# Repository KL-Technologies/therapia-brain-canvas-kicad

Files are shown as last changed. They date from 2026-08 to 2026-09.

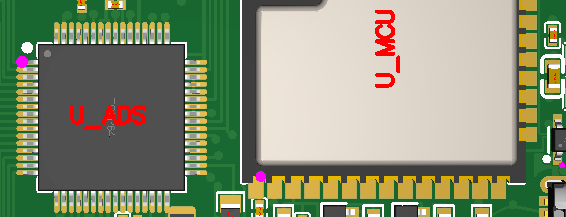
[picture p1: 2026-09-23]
fab/jlc_cart_2026-09-23_y9/08_placement_ads_mcu_pin1.png

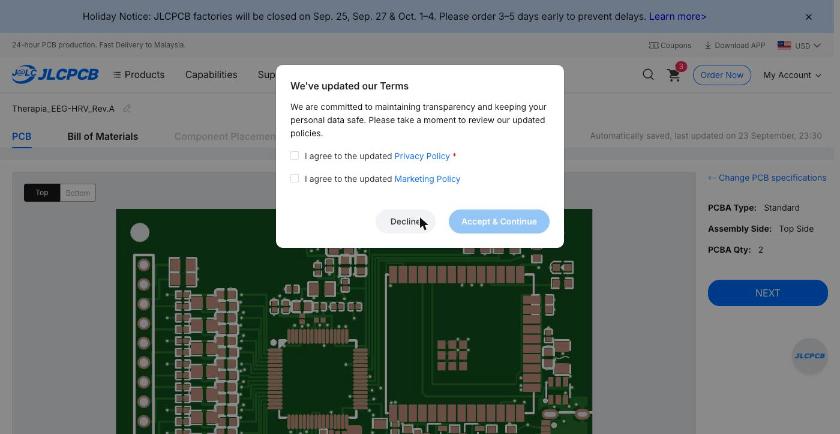
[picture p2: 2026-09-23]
fab/jlc_cart_2026-09-23_y9/03_terms_update_modal.jpg

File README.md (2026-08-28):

# brain_canvas_kicad

Brain Canvas Rev.A (Therapia EEG/HRV board) を **EasyEDA Pro から KiCad 10 へ移行**し、
以後のレイアウト修理・製造データ出力を KiCad 側でヘッドレスに回すためのパイプライン。

対象基板: 4層 / 61.8236 × 45.0088 mm (2434 × 1772 mil) / 部品 131 個・全数 Top 実装。

## 前提

| 名前 | パス | 用途 |
|---|---|---|
| `KC` | `/Applications/KiCad/KiCad.app/Contents/MacOS/kicad-cli` | DRC・Gerber 等の CLI（10.0.5） |
| `KPY` | `/Applications/KiCad/KiCad.app/Contents/Frameworks/Python.framework/Versions/Current/bin/python3` | `pcbnew` を持つ Python（3.9.13） |
| system `python3` | `/usr/bin/python3`（3.9.6） | 純 JSON 処理のステップ |

環境変数 `KC` / `KPY` で上書きできる。スクリプトは**標準ライブラリのみ**・**冪等**（再実行しても同じ結果）。
GUI は一切使わない。

## 使い方

```sh
./run.sh              # 未完のステップから順に実行（ゲート pass 済みは飛ばす）
./run.sh --status     # ゲート一覧を表示するだけ
./run.sh --force      # S0 から全部やり直す
./run.sh --from S2    # 指定ステップから再実行
./run.sh --no-commit  # git commit を作らない
```

ゲートが落ちると `exit 1` で停止する。**S1 の失敗は「.epro がまだ無い」待ち状態**であって
不具合ではない（`STATUS.md` 参照）。各ステップ成功後に `git commit` が入る。

```sh
python3 scripts/99_selftest.py   # 合成 .epro でパーサ／パッチャの動作確認（KiCad 不要）
```

## ステップ

| ID | スクリプト | 実行系 | 内容 | ゲート |
|---|---|---|---|---|
| S0 | `scripts/00_env_check.sh` | bash | kicad-cli / pcbnew / `EASYEDAPRO` / `ZONE_FILLER` / `drc --refill-zones` の存在確認 | `gates/S0.json` |
| S1 | `scripts/05_find_epro.sh` | bash + python3 | `~/Downloads` `~/Desktop` `~/Documents` `therapia-device/` から `.epro` / `.epro2` を捜して `import/` へ複製し sha256 記録 | `gates/S1.json` |
| S1B | `scripts/06_epro2_to_epro.py` | python3 | `.epro2`（EasyEDA Pro 3.2）を KiCad が読める旧 `.epro` へ変換。旧形式が既にあれば何もしない | `gates/S1B.json` |
| S2 | `scripts/10_epro_inventory.py` | python3 | `.epro` を自前パースして EasyEDA 側の員数表を作る | `gates/inventory_easyeda.json` |
| S2 | `scripts/11_import_epro.py` | KPY | パッチ段階を変えながら `PCB_IO_MGR.Load(EASYEDAPRO)` → `Save(KICAD_SEXP)` → パッド網の補修 → DRC | `board/*.kicad_pcb` |
| S2 | `scripts/12_verify_import.py` | KPY | `pcbnew.LoadBoard` で読み直して EasyEDA 側と突合 | `gates/S2.json` |
| S2B | `scripts/20_netlist_contract.py` | python3 | 回路図ネットリスト TSV を契約化し、PCB との差分（＝ECO-1 の残作業）を列挙 | `gates/S2B.json` |
| S4a | `scripts/13_fix_import.py` | KPY | NPTH 6 穴を合成（M2 ×4・USB-C ペグ ×2）し、開いていた基板外形を閉じる | `gates/S4a.json` |
| S3 | `scripts/14_make_rules.py` | python3 | JLC 4 層ルールを `.kicad_pro` / `.kicad_dru` / `.kicad_pcb` の `(setup)` へ生成 | — |
| S3 | `scripts/15_gate_s3.py` | python3 + KC | DRC ベースラインを取り、**ルールが L1〜L4 を実際に検出することを検定** | `gates/S3.json` |
| S4 | `scripts/19_make_parts_table.py` | python3 | 旧 BOM ＋ ECO-2/3 の置換表から `data/parts_lcsc.csv`（135 行）を生成 | — |
| S4 | `scripts/20_apply_eco.py` | KPY + KC | ECO-1/2/3 を PCB へ適用し、契約と全パッド突合、ゾーン再充填して DRC | `gates/S4.json` |
| S5_uuids | `scripts/26_fix_uuids.py` | python3 (+KPY) | 重複 KIID 2,625 個を採番し直す。**これより前の DRC レポートはアイテムの同定が信用できない** | `gates/S5_uuids.json` |
| S5_L1 | `scripts/30_repair_L1.py` | KPY + KC | AMS1117 を取付穴 H4 から退避させ、4 ピンを繋ぎ直す | `gates/S5_L1.json` |
| S5_L2 | `scripts/31_repair_L2.py` | KPY + KC | CHASSIS_GND を H1 の外へ引き直す | `gates/S5_L2.json` |
| S5_L3 | `scripts/32_repair_L3.py` | KPY + KC | ESP_TXD を分割し、H4 に掛かる中央だけ引き直す | `gates/S5_L3.json` |
| S5_L4 | `scripts/33_repair_L4.py` | KPY + KC | USB-C ペグ穴 PEG1/PEG2 を空け、J1 の GND ランドを詰める | `gates/S5_L4.json` |
| S5_L5 | `scripts/34_repair_L5.py` | KPY + KC | 残りの近接を幾何から洗い出して解消 | `gates/S5_L5.json` |
| S5_mask | `scripts/35_mask_bridges.py` | KPY + KC | 合体したレジスト開口をパッド個別マージンで分ける | `gates/S5_mask.json` |
| S6 | `scripts/40_drc_loop.py` | python3 + KPY + KC | DRC → 修正 → DRC を clean になるまで反復 | `gates/S6.json` |
| S7a | `scripts/45_apply_eco5_and_bom.py` | KPY + KC | ECO-5（`C_BIAS_INV` pad2 を GND → BIAS_OUT_INT）と BOM 修正・DNP 2 点を反映 | `gates/S7a.json` |
| S7b | `scripts/46_analog_untouched.py` | KPY | 取り込み直後の基板とアナログ 40 ネットを突合し、差分の由来を記録から特定 | `gates/S7b.json` |
| S7c | `scripts/48_improve_vcap3.py` → `47_layout_quality.py` | KPY | バイパス C を「より近く・ビア無し」の位置へ移せるか試し、ADS1299 チェックリスト J1〜J11 を実測 | `gates/S7c.json` |
| S8 | `scripts/43_fix_pth_mask.py` → `49_normalize_layer_names.py` → `60_export_fab.sh` → `61_make_bom_cpl.py` → `63_gate_s8.py` | KPY + KC + python3 | PTH のレジスト開口を復旧し、レイヤ名を正規化してから Gerber・ドリル・BOM・CPL・プレビューを出力し、**自前パーサ**で検査 | `gates/S8.json` |
| S7 | `scripts/50_final_check.py` | KPY + KC | **ACCEPTANCE A〜G を 32 項目で判定** | `gates/S7.json` |

**S8 が S7 より先なのも意図的**。ACCEPTANCE の D〜G は S8 が出力した製造データを
読むので、先に出力しないと最終ゲートに検査対象が無い。

**S4a が S3 より先なのは意図的**。取付穴が NPTH になるまで hole clearance ルールに
引っかかる穴が存在せず、S3 のゲート（L1/L2/L4 の検出）が成立しないため。

**S5_uuids が L1 より先なのも意図的**。KiCad の DRC は違反アイテムを KIID で保存して
レポート時に引き直すので、KIID が重複していると**別の部品を名指しする**。
取り込み直後の基板は 231 個の uuid を共有していた（1 個は 38 部品で共有）。

### 共通ライブラリ

| ファイル | 中身 |
|---|---|
| `scripts/lib/epro.py` | `.epro` のパースとパッチ、ゲート JSON の読み書き |
| `scripts/lib/route.py` | 銅箔の空間索引・衝突判定、スタブ除去、2 層ルータ（直線→L 字→via ホップ）、部品配置探索 |
| `scripts/lib/maze.py` | 2 層 A* ルータ。via 遷移つき、DRC と同じ `SHAPE::Collide` で判定し、経路は採用前に線分ごとに再検証してから直線化する。ペグ穴まわりのように「直線も L 字も via ホップも無い」場所はこれでないと通らない |
| `scripts/lib/repair.py` | S5/S6 共通。ルール値、穴までの距離、接続性（`net_components`）、修理プリミティブ（via 退避・端点退避・トラック分割迂回・穴の排除）、ゲート雛形 |
| `scripts/lib/viol.py` | DRC レポートを作業リストに変換する。ただし**位置は信用しない**（アイテム自身のアンカーが入っている） |
| `scripts/lib/drc.py` | DRC レポートの署名比較。`kicad-cli pcb drc` は同一入力で 525〜531 件と揺れるので、件数ではなく（種別, ネット集合）で比較する |
| `scripts/lib/xlsx.py` | 旧 BOM/CPL の xlsx を標準ライブラリだけで読む |
| `scripts/lib/gerber_parse.py` | RS-274X と Excellon を**自前で**読む（標準ライブラリのみ）。C/R/O/P アパーチャ、KiCad の `RoundRect` マクロ、G36/G37 リージョン、G75 円弧、LPD/LPC 極性。未知のマクロは外接円に落とす（穴クリアランス検査で銅を過大評価する側なので、誤警報は出しても見逃しは出さない）。**KiCad に自分の出力を読み直させても、自分と矛盾していないことしか分からない** — S8 の PTH レジスト欠落はこれで見つかった |

`import/` に**正規の旧 `.epro`** と `.epro2` が両方あるときは、必ず旧 `.epro` を使う（変換を挟まないぶん確実）。
`.converted.epro` は最下位。

## 落とし穴 3 つ（実測で確認済み）

### 1. `.epro2` は KiCad 10.0.5 では読めない。しかもエラーが出ない

EasyEDA Pro 3.2 の書き出しは `project2.json` ＋ 単一の `.epru`（全ドキュメントを
`{ヘッダ}||{本体}|\n` で連結したログ形式）。KiCad のバイナリに `project2.json` / `epru` /
`epro2` の文字列は 1 つも無く、`PCB_IO_MGR.Load` に渡すと **例外を出さずに空の基板
（フットプリント 0・ネット 1）を返す**。気づかず先へ進める形の失敗なので、S1 で形式を判定し
S1B で変換する。変換で運ばないもの:

- `RULE` — 3.2 の設計ルールは入れ子構造で旧形式への対応が付かない（これを誤ると #24303 を踏む）。値は `contract/easyeda_rules.json` に出すので S3 が `.kicad_pro` へ意図して書き写す
- `POURED` — EasyEDA が計算済みの銅箔充填。KiCad が `drc --refill-zones` で作り直すし、S3 は編集後にどのみち再充填が要る

### 2. 同じ番号のパッドは 1 つしかネットが付かない

KiCad は `PAD_NET` を `FindPadByNumber()` で当てるので、**同一番号のパッドが複数あると最初の 1 枚
にしか付かない**。この基板では ESP32 のサーマルパッド（`39` ×9）と USB-C のシェル脚
（`13`/`14` ×2）が該当し、GND が 10 パッド落ちる。`11_import_epro.py` が取り込み後に
EasyEDA 側の表を全パッドへ再適用して直す（`logs/pad_net_repair.json`）。

### 3. `kicad-cli pcb drc` はコマンドサンドボックス内では動かない（かつ非決定的）

サンドボックス下では `Swift/SwiftNativeNSArray.swift:78: Fatal error: Array index out of range`
で落ちる（Swift のエラーは表面的な症状で、原因は macOS のサービスが塞がれていること）。
`export gerbers` などほかのサブコマンドは影響を受けない。**DRC はサンドボックス外で実行する。**
通常のターミナルからは普通に動く。

さらに **DRC の出力は同一の基板に対しても揺れる**。実測で 525 / 528 / 531 件。
同じ物理的問題を代表する要素の選ばれ方が変わるためで、たとえば

```
run A   Track [V_NLDO_IN] on Bottom Layer, length 2.2860 mm  <-> Via [VNEG5]
run B   Track [V_NLDO_IN] on Bottom Layer, length 0.2543 mm  <-> Via [VNEG5]
```

は同じ 1 箇所を指している。したがって**件数で合否を判定してはいけない**。
`scripts/lib/drc.py` の署名（種別 ＋ ネット集合）で比較する。
部品参照を署名に含めてはいけない ── track（部品名を含まない）と pad（含む）が
入れ替わるだけで、無変更の基板が「新規 10 件・解決 10 件」に見える。

### 4. KIID は一意ではない（この基板では 231 個が重複）

EasyEDA インポータがライブラリ部品の全インスタンスに同じ KIID を振る。実測で
**38 個の部品が 1 個の uuid を共有し、その 38 個の 1 番パッドがまた別の 1 個を共有**。
KiCad は uuid の一意性を前提にしていて、`BOARD::GetItem(KIID)` は最初に見つけた
ものを返す。

これが効いてくるのは **DRC レポート**で、KiCad は違反アイテムをポインタではなく
KIID で保存し、レポートを書くときに引き直す。重複があるとレポートは
**実在しない組み合わせを名指しする** ── 9.3 mm 離れたパッド同士の
`solder_mask_bridge`、8.9 mm 離れたパッド同士の 0.0420 mm `clearance` など。
**種別と件数は常に正しく、間違うのはアイテムの同定だけ。**

`scripts/26_fix_uuids.py` が重複を採番し直す（`.kicad_pcb` は uuid を相互参照
しないので安全。基板の幾何とネットが不変であることを検証してから保存する）。
**取り込みからやり直す場合は L1 より先にこれを通すこと。**

### 5. pcbnew の SWIG プロキシは `id()` で比較できない

基板から同じパッドを 2 回取り出すと別のプロキシが返り、`id()` が一致しない。
無視リストや訪問済み集合は `scripts/lib/route.uid()` で持つこと
（KIID 単独では上記のとおり一意でないので、パッドと部品は reference と
フットプリント相対座標を足した鍵になっている）。関連して:

- `board.Remove()` は board 直下の要素に使うと以後 `GetFootprints()` が生の
  `SwigPyObject` を返すようになる。**`RemoveNative()` を使う**
- `pcbnew.FOOTPRINT(src)` は KIID ごと複製する（複製先のパッドが元と同じ uuid を持つ）。
  `m_Uuid` は書き込み不可で `FixUuids()` も効かないので、新規部品はゼロから組み立てる
- 同一プロセスでの 2 回目の `LoadBoard`、および `SaveBoard` の後は基板を走査できない。
  計測は保存前に済ませる

## KiCad 側インポータの既知バグと回避

`.epro` は ZIP の中に JSON Lines 文書（`project.json` / `*.epcb` / `*.esch` / `*.esym` / `*.efoo`）が入る形式
（仕様: <https://dev-docs.kicad.org/en/import-formats/easyeda/index.html>）。
KiCad 10 のインポータは現行の EasyEDA 出力に対して 2 つ落とし穴がある。

| KiCad issue | 症状 | 回避 |
|---|---|---|
| #24303 | パースが `type must be number, but is array` で落ちる。EasyEDA 2.2+ の `RULE` レコードが payload を 1 段深い dict に入れるため | `RULE` の `ruleData` を旧形式へ平坦化（clearance=`ruleType "1"` / track width=`"3"`） |
| #19021 | 読み込みは成功するのに**全パッド・全トラックが 1 ネットに融合**する。新しい出力が先頭の `NET` 宣言を落とすため | 各プリミティブの net 名フィールドを走査して、未宣言のネットを `["NET", name]` としてヘッダ直後に再注入 |
| （併発） | `std::out_of_range: map::at` で落ちる | 文書内の CRLF を LF へ正規化 |

手法は <https://github.com/enkhbold470/epro2kicad> を参照して `scripts/lib/epro.py` に自前実装した
（外部依存としては入れていない）。`11_import_epro.py` は

`raw` → `newlines` → `newlines+rules` → `newlines+rules+nets`

の 4 段階をそれぞれ**別プロセスの KPY で**試し（パーサが abort しても子プロセスだけが死ぬ）、
`gates/inventory_easyeda.json` の員数と突き合わせて**一番手を加えていないのに員数が合う段階**を採用する。
採用結果は `logs/import_attempts.json` / `logs/import_summary.json` に残る。

## 単位と座標

- EasyEDA Pro の PCB 内部単位は **mil**、**y は下向きが負**。`mm = mil × 0.0254`。
- KiCad は内部単位 nm、**y は下向きが正**。したがって EasyEDA の点 `(x, y)` は KiCad の `(x, −y)` に対応する。
- さらに KiCad は取り込み時に基板を **(120, 80) mm** 平行移動する（実測値。`gates/S2.json` の
  `board_offset_mm` に毎回記録される）。**S3 以降で EasyEDA 由来の座標メモ
  （`11_rev_a_eco_2026-08-16.md` の L1〜L6 など）を KiCad 上で使うときは
  `kicad = (x + 120, −y + 80)` [mm] で読み替えること。**
- 部品ローカル座標 → 基板座標は単純な回転（軸反転なし）:
  `bx = cx + lx·cosθ − ly·sinθ` / `by = cy + lx·sinθ + ly·cosθ`。
  `10_epro_inventory.py` が毎回 131 部品分を `fab_2026-08-16` の CPL（Pad X/Pad Y）と突き合わせて
  検証する（`cpl_crosscheck.placement_transform_verified`）。

## ディレクトリ

```
import/    .epro 原本（SHA256SUMS 付き）と patched.epro
board/     KiCad 成果物 (.kicad_pcb / .kicad_pro)
scripts/   パイプライン本体（lib/ は共通パーサ）
gates/     各ステップの合否 JSON と員数表
contract/  ネットリスト（S3 の契約）
fab/       製造データ（S8）。zip・BOM・CPL・プレビュー・実装図・README_発注手順.md
logs/      実行ログ・DRC 出力・パッチ試行履歴
```

## 参照する既存資料（読むだけ・変更しない）

- `../cerelog_research/11_rev_a_eco_2026-08-16.md` — ECO-1〜3 とレイアウト修理 L1〜L6 の正本
- `../cerelog_research/PROJECT_STATUS.md` — 経緯・ネット員数の記録
- `../cerelog_research/fab_2026-08-16/` — 旧版の Gerber / BOM / CPL。CPL の 131 designator と
  回転角は S2 の独立参照として自動で突合される

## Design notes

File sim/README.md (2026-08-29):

# `sim/` — headless SPICE for Brain Canvas Rev.A

Circuit simulation of the board as the contract netlist wires it, run
head­lessly from Python. No GUI, no ngspice CLI, no LTspice, no PySpice.

```
python3 sim/run_all.py            # every case -> gates/S3_sim.json
python3 sim/cases/drl_loop.py     # one case  -> sim/out/drl_loop.json
python3 sim/lib/ngspice_ctypes.py # self-test the engine
```

Use `/usr/bin/python3` (3.9, arm64). The KiCad-bundled interpreter at
`/Applications/KiCad/KiCad.app/Contents/Frameworks/Python.framework/Versions/Current/bin/python3`
works identically.

## The engine

KiCad 10.0.5 ships the full ngspice shared library, so there is no need to
install anything:

```
/Applications/KiCad/KiCad.app/Contents/Frameworks/libngspice.0.dylib   ngspice-45.2
/Applications/KiCad/KiCad.app/Contents/PlugIns/sim/ngspice/*.cm        XSPICE code models
```

`sim/lib/ngspice_ctypes.py` drives it through the classic sharedspice API
(`ngSpice_Init` / `ngSpice_Command` / `ngGet_Vec_Info`). Both interpreters
`dlopen` it without any codesign or Library Validation trouble — the library
is already signed as part of the KiCad bundle, and both it and the
interpreters are arm64.

Every netlist runs in **its own subprocess**. libngspice keeps global state
and can tear the process down on a fatal error, so isolating each run makes a
blown-up simulation a recoverable event and guarantees circuit N+1 inherits
nothing from circuit N.

## Layout

| Path | What it is |
|---|---|
| `lib/ngspice_ctypes.py` | ctypes driver; `run_netlist(deck) -> SimResult` |
| `lib/extract_subckt.py` | contract netlist + BOM → SPICE elements, with DC-bias derating |
| `lib/simutil.py` | measurement helpers (ripple, settling, phase margin) and the result format |
| `models/behavioral.lib` | behavioural models (TLV70025, AMS1117, ADS1299 BIAS amp, S8050) |
| `models/vendor/` | TI's unencrypted PSpice models for LM2664 and TPS723xx, used **unmodified**, plus thin board-pinout wrappers |
| `models/PROVENANCE.md` | **read this before believing a number** |
| `data/cap_derating.json` | per-LCSC MLCC DC-bias retention, ESR, ESL |
| `cases/*.py` | one script per test, each writing `sim/out/<case>.json` |
| `run_all.py` | runs them all, writes `gates/S3_sim.json` |

## Nothing is typed in twice

Component values and connections are read from
`contract/netlist_easyeda_api_2026-08-28.tsv` and `data/parts_lcsc.csv`, with
`contract/contract_overrides.json` (ECO-5) applied by default. A case script
asks for a set of designators or nets and gets SPICE back:

```python
from extract_subckt import Design
d = Design()                       # as built (overrides applied)
d.numeric_value("R_BIAS_FB")       # 1e6   -- "1M" is megohms, not milliohms
text, report = d.spice(nets=["AVSS"], bias={"AVSS": -2.5, "GND": 0.0})
```

`report["skipped"]` lists everything that was *not* emitted and why, so a
case can prove it did not silently drop a component.

## Vendor models

TI's unencrypted PSpice models are used for the two devices where one exists:

* **LM2664** — SNVMBY1, verbatim. Real oscillator, real 1.25 Ω switches,
  real SD comparator.
* **TPS72325** — SLVMBZ8 (the adjustable TPS72301), re-parameterised to
  −2.5 V. Its enable term is `IF(ABS(V(enb)) > 1.5)`, which is how the
  simulation confirms the board's EN wiring rather than assuming it.

`TLV70025`'s TI model is encrypted and the AMS1117 has none, so those two are
behavioural. `models/PROVENANCE.md` has the full table.

ngspice parses TI's PSpice text unmodified once `set ngbehavior=psa` is
issued **before** the deck is sourced — `run_netlist(..., pre_commands=[...])`.
A `.options` line inside the deck is too late.

## Capacitor derating is not optional here

Every ceramic on this board is class II. `C_NLDO_OUT` is a 2.2 µF 6.3 V X5R
in 0402 biased at 2.5 V; simulating it as 2.2 µF would be self-deception.
The harness derates from `data/cap_derating.json` and totals what is really
there — AVDD and AVSS each lose about 52 % of their marked
capacitance at typical 25 C bias, and about 64 % in the worst corner.

Nine of the eleven rows are **fetched Samsung curves** (weblib, 25 °C,
2026-08-29) and are flagged `trusted: true`; one is a documented estimate and
says so. Each row also carries a worst-case curve — the measurement times the
tolerance low limit times 0.85 for the temperature coefficient — and
`ldo_stability.py` reports both corners, plus a current-versus-proposed BOM
comparison.

Three things the real curves show that a rule of thumb would miss: a 50 V
1206 part still loses 20 % at 5 V; a 25 V 0402 1 µF loses 38 % at 3.3 V (that
is C_EN_DLY, and it is why the ESP32 reset-delay check fails); and a 100 µF
6.3 V 1206 is only 91 µF before any bias is applied.

## Cases

| Case | Asks |
|---|---|
| `power_tree_startup.py` | USB hot-plug at 4.75 / 5.25 V through F1 → AMS1117, TLV70025, LM2664 → TPS72325. Rail values, rise, overshoot, AVSS ripple, and whether TPS72325's EN is asserted |
| `ldo_stability.py` | Loop gain and load-step settling for both analog LDOs on the *derated* output capacitance |
| `drl_loop.py` | ADS1299 BIAS loop through an electrode/body model at 5 k / 20 k / 100 kΩ skin, with the BIAS amp's unpublished GBW swept 10 kHz…1 MHz. Also runs the pre-ECO-5 wiring to quantify what that ECO bought |
| `esp32_autoreset.py` | DTR#/RTS# truth table against esptool's reset sequence, ESP32 pin levels against absolute maximum, and the power-on EN delay |

## ngspice traps worth knowing

Found the hard way while building this; all are silent failures.

1. **`limit(x, lo, hi)` in a B-source returns 0 and raises no error.** It is
   not an ngspice B-source function. Use `min(max(x, lo), hi)`.
2. **`GND` is a reserved global alias for node 0.** A sub-circuit terminal
   named `GND` is silently shorted to ground. The models here use `GNDP`.
3. **A `? :` step on a node that multiplies a current is a discontinuity the
   solver cannot cross** — it shows up as `Timestep too small`. Enable
   comparators here ramp over a narrow window instead.
4. **A fixed DC current sink on a rail that is still at 0 V** drives the t=0
   operating point to kilovolts through whatever leakage resistor the model
   has, and the transient never starts. Loads are gated on their own rail.
5. **An error amplifier with no anti-windup** runs away while its regulator
   is disabled and then demands kiloamps on the first step after enable.
6. `.options rshunt=1e9 cshunt=2f` cures most remaining stiffness.
7. **`set ngbehavior=psa` must be issued before the deck is sourced**, not as
   a `.options` line inside it.
8. **ngspice 45.2's PSpice mode has a start-up race** that kills the library
   roughly half the time with `failed to parse .func in: .func pwr(x a)`.
   Loading the XSPICE code models makes it much less likely (3 in 6 versus
   6 in 6 without); `run_netlist` retries eight times to cover the rest.
   Because of this, PSpice mode is switched on only for decks that actually
   contain a vendor model.
9. **Passing the same node to two formals of a sub-circuit** can stall a
   transient. The board ties LM2664 SD to V+ and TPS72325 EN to IN, so both
   vendor wrappers insert a 1 mΩ isolation resistor.
10. TI's vendor models are stiff enough that they will not converge inside
    the full power-tree deck; each runs in its own focused deck instead.

## Possible future replacement

[`spicelib`](https://github.com/nunobrum/spicelib) offers a common API over
ngspice and LTspice plus Monte Carlo / worst-case tooling, and would be a
reasonable replacement for `lib/ngspice_ctypes.py` if tolerance analysis is
ever wanted. Not adopted now: it needs a `pip` install, which the command
sandbox blocks, and the ctypes driver already does what these cases need.

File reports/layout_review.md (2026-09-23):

# レイアウト品質レビュー（S7c）

`docs/ads1299_layout_checklist.md`（一次資料ベース、opusQ3）の **J1〜J11** と、S7 への申し送りが挙げた点を、**基板から実測**して答えたもの。

> **距離に閾値を置いていないのは意図的。** チェックリストが冒頭で 「TI はデカップリングの配置距離を一切数値で示していない。『◯ mm 以内』という数字を作ってはいけない」と釘を刺している。したがって距離は**測定値として載せるだけ**で合否にしない。TI が規則として書いているのは J1（バイパス C と IC の間にビアを置かない・同一層）なので、合否はそちらで取る。

## 1. デカップリング — J1（ビアを挟まない・同一層）

DS §12.1: *"Do not place vias between bypass capacitors and the active device. Placing the bypass capacitors on the same layer as close to the active device yields the best results."*

> **J1 が効くのは配線で配る電源だけ。** この基板でベタになっているのは `AVDD`, `AVSS`, `CHASSIS_GND`, `GND`, `USB_5V`, `VDD_ESP`。ベタ電源はパッド→ビア→ベタ→ビア→ピンで繋がるので、「経路にビアがある」のはスタックアップの性質であってレイアウトの誤りではない。配線で配っている **VCAP1〜4 と VREFP** が J1 の対象。

| コンデンサ | ADS ピン | 配り方 | 直線 [mm] | 銅箔経路 [mm] | 経路上のビア | 同一層 | J1 | 戻り側 | 戻り via まで [mm] |
|---|---|---|---|---|---|---|---|---|---|
| C_AVDD_P19 | 19 (AVDD) | ベタ | 3.10 | 配線経路なし | — | はい | — | GND | 0.83 |
| C_AVDD_H | 21 (AVDD) | ベタ | 8.47 | 配線経路なし | — | はい | — | GND | 0.77 |
| C_AVDD_B | 21 (AVDD) | ベタ | 8.62 | 配線経路なし | — | はい | — | GND | 0.78 |
| C_AVDD_H | 22 (AVDD) | ベタ | 8.39 | 配線経路なし | — | はい | — | GND | 0.77 |
| C_VREFP_10u | 24 (VREFP) | 配線 | 6.46 | 9.40 | 0 | はい | OK | AVSS | 1.03 |
| C_VREFP_100n | 24 (VREFP) | 配線 | 3.40 | 6.47 | 0 | はい | OK | AVSS | 1.96 |
| C_VREFP_10n | 24 (VREFP) | 配線 | 2.93 | 2.65 | 0 | はい | OK | AVSS | 1.97 |
| C_VCAP4 | 26 (VCAP4) | 配線 | 1.36 | 1.36 | 0 | はい | OK | AVSS | 1.83 |
| C_VCAP1 | 28 (VCAP1) | 配線 | 9.89 | 17.40 | 2 | はい | **NG** | AVSS | 0.95 |
| C_VCAP1_H | 28 (VCAP1) | 配線 | 1.36 | 1.36 | 0 | はい | OK | AVSS | 2.51 |
| C_VCAP2 | 30 (VCAP2) | 配線 | 1.53 | 1.53 | 0 | はい | OK | AVSS | 0.94 |
| C_AVDD_P36 | 56 (AVDD) | ベタ | 16.29 | 配線経路なし | — | はい | — | GND | 1.02 |
| C_AVDD_P31 | 56 (AVDD) | ベタ | 14.13 | 配線経路なし | — | はい | — | GND | 2.10 |
| C_AVDD1_1u | 54 (AVDD1) | ベタ | 4.10 | 配線経路なし | — | はい | — | AVSS | 1.64 |
| C_AVDD1_100n | 54 (AVDD1) | ベタ | 3.95 | 配線経路なし | — | はい | — | AVSS | 3.65 |
| C_AVDD1_10n | 54 (AVDD1) | ベタ | 4.98 | 配線経路なし | — | はい | — | AVSS | 5.87 |
| C_AVDD1_10u | 54 (AVDD1) | ベタ | 5.54 | 配線経路なし | — | はい | — | AVSS | 1.41 |
| C_VCAP3 | 55 (VCAP3) | 配線 | 2.10 | 2.10 | 0 | はい | OK | AVSS | 2.91 |
| C_VCAP3_H | 55 (VCAP3) | 配線 | 3.36 | 4.39 | 2 | はい | **NG** | AVSS | 2.75 |
| C_AVDD_P59 | 59 (AVDD) | ベタ | 4.50 | 配線経路なし | — | はい | — | GND | 0.57 |
| C_DVDD_P58 | 48 (DVDD) | 配線 | 11.48 | 22.11 | 0 | はい | OK | GND | 0.65 |
| C_DVDD_H | 48 (DVDD) | 配線 | 12.09 | 17.14 | 0 | はい | OK | GND | 0.70 |
| C_DVDD_P40 | 50 (DVDD) | 配線 | 6.23 | 13.67 | 0 | はい | OK | GND | 0.70 |
| C_DVDD_10u | 50 (DVDD) | 配線 | 9.89 | 18.01 | 0 | はい | OK | GND | 0.72 |
| C_AVSS_P17 | 20 (AVSS) | ベタ | 6.28 | 配線経路なし | — | はい | — | GND | 0.60 |
| C_AVSS_H | 20 (AVSS) | ベタ | 9.49 | 配線経路なし | — | はい | — | GND | 0.57 |
| C_AVSS_P30 | 32 (AVSS) | ベタ | 9.29 | 配線経路なし | — | はい | — | GND | 0.63 |
| C_AVSS_P37 | 57 (AVSS) | ベタ | 16.22 | 配線経路なし | — | はい | — | GND | 0.58 |
| C_AVSS_P60 | 58 (AVSS) | ベタ | 17.79 | 配線経路なし | — | はい | — | GND | 0.58 |
| C_AVSS_B | 58 (AVSS) | ベタ | 19.23 | 配線経路なし | — | はい | — | GND | 0.73 |

**配線で配る電源のうち、ビアを挟んでいるのは 2 経路。**

- `C_VCAP1` → ADS ピン 28（VCAP1）: ビア 2 個・銅箔 17.40 mm
- `C_VCAP3_H` → ADS ピン 55（VCAP3）: ビア 2 個・銅箔 4.39 mm

## 2. VREFP の 3 個は近い順に並んでいるか

| コンデンサ | ADS pin24 から [mm] |
|---|---|
| C_VREFP_10n | 2.93 |
| C_VREFP_100n | 3.40 |
| C_VREFP_10u | 6.46 |

## 3. J2 — AVDD1 / AVSS1 のスター接続

DS §11: *"AVDD1 provides the supply to the charge pump block and has transients at fCLK. Therefore, star connect AVDD1 to the AVDD pins and AVSS1 to the AVSS pins."*

**これは銅箔ではなくネットリストで決まる。** TI が求めているのは AVDD1 / AVSS1 を**独立したネットにして**、細い専用配線で AVDD / AVSS に 1 点で繋ぐこと。この基板の回路図はピン 54 を `AVDD` に、ピン 53 を `AVSS` に直結しており、**そもそも別ネットになっていない**。したがって銅箔をどう引いてもスター接続にはならず、**PCB 側で直せる問題ではない（回路図の変更＝Rev.B 案件）**。

| ピン | 名前 | 回路図のネット | 独立ネット | パッド下のゾーン | 所見 |
|---|---|---|---|---|---|
| 54 | AVDD1 | `AVDD` | **いいえ** | In1.Cu=GND, In2.Cu=AVDD | shares the AVDD net and the AVDD plane -- a star connection would need a separate AVDD1 net in the schematic (Rev.B) |
| 53 | AVSS1 | `AVSS` | **いいえ** | In1.Cu=GND, In2.Cu=AVDD | shares the AVSS net and the AVSS plane -- a star connection would need a separate AVSS1 net in the schematic (Rev.B) |

> **影響**: ADS1299 は内部チャージポンプを 2.048 MHz で回しており、そのリップルが AVDD / AVSS 全体に載る。Rev.A では受容し、火入れ時に AVDD のリップルを実測して Rev.B の判断材料にすること。

## 4. J5 / B-4 — SPI と USB 差動のリターン経路

DS §12.1 は「グラウンドプレーンが切れていたり他の配線がリターン電流を妨げていたりすると、電流は遠回りを強いられ放射が増える」と述べている。判定は **直下の In1 が GND で埋まっていること**と**In1 に他の配線が無いこと**。

> ベタが無い点をそのまま数えると**ビアのアンチパッド**まで「分割」に見える。実測 187 点はすべて**その配線自身のビア**から 0.2 mm 以内だった（リターン電流もそのビアで層を替える）。そこで欠落は原因別に分類し、**ビアで説明できない空白だけ**を断絶とする。

| ネット | サンプル点 | 自ネットのビア | 他ネットのビア | **原因不明の空白** | 内層配線の上 | 判定 |
|---|---|---|---|---|---|---|
| ADS_SCLK_LOC | 354 | 0 | 0 | **0** | 0 | 連続 |
| ADS_DIN_LOC | 56 | 0 | 0 | **0** | 0 | 連続 |
| ADS_DOUT_LOC | 301 | 0 | 0 | **0** | 0 | 連続 |
| ADS_CS_N | 772 | 40 | 0 | **0** | 0 | 連続 |
| ADS_DRDY_N | 976 | 22 | 0 | **0** | 0 | 連続 |
| USB_DP | 351 | 61 | 0 | **0** | 0 | 連続 |
| USB_DM | 474 | 51 | 0 | **0** | 0 | 連続 |

## 5. 入力ネットの直下（In2 電源ベタ）

In2 は電源ベタ（AVDD / AVSS / USB_5V / VDD_ESP ほか）。

> **表の「またぐ」は問題ではない。** 入力配線のリターン電流が流れるのは**直下ではなく最も近いリファレンス面**で、この基板ではそれが **In1（GND、1 枚もの・2498.3 mm²・基板面積の 90%）**。In1 に切れ目が無い以上リターン経路は連続しており（第 4 節で実測）、In2 の境界越えはリターンの断絶にはならない。下表は「入力の下に何があるか」の記録であって合否ではない。

| 入力 | またぐ領域数 | 遷移回数 | 領域 |
|---|---|---|---|
| IN1P | 3 | 2 | AVSS, AVDD, (no fill) |
| IN1N | 3 | 8 | (no fill), AVSS, AVDD |
| IN2P | 3 | 2 | AVSS, (no fill), AVDD |
| IN2N | 3 | 8 | (no fill), AVSS, AVDD |
| IN3P | 3 | 2 | AVSS, (no fill), AVDD |
| IN3N | 3 | 8 | AVSS, (no fill), AVDD |
| IN4P | 3 | 2 | AVSS, (no fill), AVDD |
| IN4N | 3 | 8 | AVSS, (no fill), AVDD |
| IN5P | 3 | 2 | AVSS, (no fill), AVDD |
| IN5N | 3 | 8 | AVSS, (no fill), AVDD |
| IN6P | 3 | 2 | AVSS, (no fill), AVDD |
| IN6N | 3 | 8 | (no fill), AVSS, AVDD |
| IN7P | 3 | 2 | AVSS, (no fill), AVDD |
| IN7N | 3 | 8 | AVSS, (no fill), AVDD |
| IN8P | 3 | 2 | AVSS, AVDD, (no fill) |
| IN8N | 3 | 8 | AVSS, (no fill), AVDD |

## 6. 差動ペアの長さ差と間隔

| ペア | P 側 [mm] | N 側 [mm] | 差 [mm] | 最小間隔 [mm] |
|---|---|---|---|---|
| IN1P/IN1N | 22.38 | 20.52 | 1.85 | 0.331 |
| IN2P/IN2N | 20.38 | 18.52 | 1.85 | 0.331 |
| IN3P/IN3N | 18.38 | 16.53 | 1.85 | 0.330 |
| IN4P/IN4N | 16.38 | 14.53 | 1.85 | 0.330 |
| IN5P/IN5N | 14.80 | 14.94 | 0.15 | 0.441 |
| IN6P/IN6N | 16.80 | 16.94 | 0.14 | 0.330 |
| IN7P/IN7N | 18.79 | 18.94 | 0.14 | 0.331 |
| IN8P/IN8N | 20.79 | 20.94 | 0.14 | 0.331 |

## 7. 入力配線とデジタル配線の最接近

| 入力 | 相手 | 層 | 間隔 [mm] |
|---|---|---|---|
| IN8N | ADS_RESET_N | F.Cu | 8.190 |
| IN8P | ADS_RESET_N | F.Cu | 9.510 |
| IN2N | ADS_RESET_N | F.Cu | 9.741 |
| IN2P | ADS_RESET_N | F.Cu | 9.754 |
| IN3P | ADS_RESET_N | F.Cu | 9.754 |
| IN1N | ADS_RESET_N | F.Cu | 9.792 |
| IN3N | ADS_RESET_N | F.Cu | 9.792 |
| IN1P | ADS_RESET_N | F.Cu | 9.856 |
| IN4P | ADS_RESET_N | F.Cu | 9.856 |
| IN4N | ADS_RESET_N | F.Cu | 9.944 |
| IN5P | ADS_RESET_N | F.Cu | 10.056 |
| IN5N | ADS_RESET_N | F.Cu | 10.192 |
| IN6P | ADS_RESET_N | F.Cu | 10.350 |
| IN6N | ADS_RESET_N | F.Cu | 10.529 |
| IN7P | ADS_RESET_N | F.Cu | 10.729 |
| IN7N | ADS_RESET_N | F.Cu | 10.886 |

## 8. 入力配線とデジタル配線の交差（層違い）

**0 箇所。**

## 9. ベタの充填状態

> **穴の数が 0 なのは「アンチパッドが無い」という意味ではない。** KiCad は充填結果の穴を外形に切り込む形で保持するので `HoleCount` は 0 を返す。実際にはビアごとにアンチパッドが開いており、第 4 節のサンプリングがそれを 187 点として拾っている。意味があるのは面積のほう。

| ネット | 層 | 外形 | 面積 [mm²] | 基板面積比 |
|---|---|---|---|---|
| CHASSIS_GND | F.Cu | 2 | 43.22 | 1.6% |
| GND | In1.Cu | 1 | 2498.30 | 89.8% |
| AVSS | In2.Cu | 5 | 842.10 | 30.3% |
| USB_5V | In2.Cu | 5 | 360.89 | 13.0% |
| VDD_ESP | In2.Cu | 1 | 329.44 | 11.8% |
| USB_5V | In2.Cu | 1 | 282.82 | 10.2% |
| AVDD | In2.Cu | 1 | 280.86 | 10.1% |
| VDD_ESP | In2.Cu | 8 | 215.61 | 7.7% |
| VDD_ESP | In2.Cu | 1 | 75.36 | 2.7% |
| VDD_ESP | In2.Cu | 4 | 0.00 | 0.0% |

**In1 = GND が 1 枚もので 2498.3 mm²（基板面積の 90%）。**分割は無く、これがすべての信号のリターン面になっている。チェックリスト B-3 が本基板に推奨した形そのもの。

**空に近いベタが 1 枚ある**: VDD_ESP@In2.Cu (4 外形, 0.0000 mm²)。VDD_ESP は 3 枚のベタに分かれており（S5 の申し送り）、そのうち 1 枚は充填の結果ほぼ何も残っていない。電気的には他の 2 枚が VDD_ESP を配っているので実害は無いが、**この 1 枚は何もしていない**。DRC も `isolated_copper` / `copper_sliver` を報告していない。

## 10. チェックリスト J3〜J11

| # | 実測 | 指針 | 判定 |
|---|---|---|---|
| J3 VCAP1 value | 100uF | 100 uF (DS Pin Functions) | OK |
| J3 VREFP bulk >= 10 uF | 10uF 50V X5R 1206 | >= 10 uF across VREFP-VREFN | OK |
| J4 VCAP1 dielectric | CL31A107MQHNNNE | C0G / NP0 / tantalum (DS 11, vibration) | **要判断** |
| J6 RESV1 (31) to DGND | GND | GND | OK |
| J7 unused analog inputs to AVDD | none unconnected | AVDD, not GND and not open | OK |
| J8 CH340C XI open, no series R on D+/D- | SOP-16 CH340C has no crystal pin (7=NC., 8=OUT#); resistors on USB_DP/USB_DM: none | internal oscillator, D+/D- straight through | OK |
| J9 USB D+/D- length delta | 11.554 mm (D+ 33.304, D- 44.858) | < 45 mm (Full Speed, H-2) | OK |
| J10 regulators and their capacitors on one side | {"AMS1117": "front", "TLV70025": "front", "TPS72325": "front", "LM2664": "front"} | all front (no part is on the back of this board) | OK |
| J11 ESP32 antenna clear of the board | module right edge 175.01 mm, board right edge 181.62 mm, overhang -6.61 mm | antenna over a cut-out or off the edge | **要判断** |

- **J4 VCAP1 dielectric**: MPN CL31A107MQHNNNE -- a class-2 dielectric here is a recorded design decision, not a pass

- **J11 ESP32 antenna clear of the board**: the module sits inside the outline, so the antenna is over board material -- a Rev.A acceptance, visible in the preview render

## 11. 改善の試行（申し送りの「人が見るべき点」3・4）

候補が採用されるのは、**現在より近く、かつビアを 1 個も使わずにピンへ届く**位置だけ。1 mm 近づけてもビアが残るなら改善ではないので採らない。

| 部品 | 現在 [mm] | 調べた位置 | 結果 |
|---|---|---|---|
| C_VCAP3 → U_ADS.55 | 2.10 | 0 | no position between 0.4 mm and 2.10 mm of the pin clears the neighbouring bodies, courtyards and copper while reaching the pin without a via |
| C_VCAP3_H → U_ADS.55 | 3.36 | 108 | no position between 0.4 mm and 3.36 mm of the pin clears the neighbouring bodies, courtyards and copper while reaching the pin without a via |
| C_VCAP1 → U_ADS.28 | 9.89 | 0 | no position between 0.4 mm and 6.00 mm of the pin clears the neighbouring bodies, courtyards and copper while reaching the pin without a via |
| C_VCAP1_H → U_ADS.28 | 1.36 | 0 | no position between 0.4 mm and 1.36 mm of the pin clears the neighbouring bodies, courtyards and copper while reaching the pin without a via |
| C_VCAP4 → U_ADS.26 | 1.36 | 0 | no position between 0.4 mm and 1.36 mm of the pin clears the neighbouring bodies, courtyards and copper while reaching the pin without a via |

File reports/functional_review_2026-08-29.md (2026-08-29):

# 独立機能レビュー 2026-08-29 — 指摘一覧と採否

- 対象: Brain Canvas Rev.A（ADS1299 + ESP32-WROOM-32UE + CH340C、USB-C 5 V 給電、61.8 × 45 mm 4 層）
- 実施: 発注（JLC カート投入済み・決済前）の直前に、パイプライン外の独立レビューとして実施
- 結論: **ブロッカーなし。** BOM のみの改善 4 件を Rev.A に反映し、残りは Rev.A 受容 / Rev.B 送り /
  ファームウェア必須事項に分類した
- 反映の正本: `data/bom_fixes_2026-08-28.json` の `fixes` 内 **`R29-1`〜`R29-5`**（status = `lead decision 2026-08-29`）
- **銅箔・フットプリント・CPL は 1 か所も変わっていない**（検証結果は末尾「再生成と検証」）

---

## 1. 指摘一覧

番号はレビュアーの採番。「採否」列が本プロジェクトの決定。

| # | 指摘 | 採否 |
|---|---|---|
| **(1)** | **CH340C の VCC = 5 V** で動作しており、その TXD および DTR#/RTS# が **5 V ロジック**で ESP32 の U0RXD / EN / IO0 を駆動する。ESP32 の絶対最大定格 3.6 V を原理的に超える。自動リセット用トランジスタ（Q_EN / Q_IO0）の **B-C 接合**を通る経路もあり、漏れ電流は **≈55〜100 µA** と見積もられる | **Rev.A 受容。** ESP32 開発ボードで広く使われている構成であり、実際にはピンの ESD クランプが VDD_ESP + 0.3 V 付近に落とす。**ボッジ案（1 枚だけ試す場合）**: `U_USB`(CH340C) の **pin16(VCC) を持ち上げて VDD_ESP に接続し、pin4(V3) を VCC に短絡**すると CH340C ごと 3.3 V で動く。**Rev.B: CH340C を 3.3 V 駆動（VCC = 3.3 V、V3 を VCC に接続）**。火入れで実測する項目を `reports/bringup_checklist.md` **5-5** として追加した（U0RXD アイドル電圧、想定 3.6〜3.9 V のクランプ） |
| **(2)** | ファームウェア: **`MISC1 = 0x00`** と、**tPOR 経過後の RESET パルス**（≥ 2 tCLK） | **必須（mandatory）。** 既に `reports/bringup_checklist.md` の **F1**（MISC1 = 0x00）・**F2**（PWDN#/RESET# High 待機のあと改めて RESET# を Low ≥1 µs → High、または RESET コマンド 0x06、18 tCLK 待ち）・**7-3**（tPOR = 2^18/2.048 MHz = 128 ms、VCAP1 > 1.1 V との遅い方）に記載済み。**2 tCLK ≈ 0.98 µs なので既存の「≥1 µs」は要求を満たす。文面は変更していない** |
| **(3)** | `C_VCAP1`（100 µF 1206）が **X5R** — Class II の圧電性、および DC バイアスによる容量低下 | **検討したが変更しない（considered, kept）。** VCAP1 は AVSS 基準で **+1.1〜1.5 V** 程度にしか上がらない（SBAS499 §11.1 の RESET 条件が「VCAP1 > 1.1 V」であることから動作点はその近傍）。**Samsung 実測カーブ（25 ℃）では `C15008` は 0 V で既に保持率 0.91、1.8 V で 0.648** → **実効 60〜65 µF 程度。TI の 100 µF 指定に対しては不足気味だが、効くのは VCAP1 の充電時間（＝起動待ち時間）が短くなる方向だけで機能影響は無い。** VCAP1 は内部基準の平滑であって**入力節点ではない**ので圧電性の効き方も (4) とは異なる。1206 で 100 µF の C0G は存在せず、タンタル化はフットプリントと信頼性の再評価を伴う。**火入れ 7-3 で立ち上がりを AVSS 基準で実測する**（`R29-5`） |
| **(4)** | `C_CM1P`〜`C_CM8N`（16 個、0603、1 nF **X7R** = C1588）は**入力節点**のコンデンサ。ADS1299 SBAS499 §12.1 は入力節点に **C0G** を指定。X7R は圧電性を持ち（装着型ではマイクロフォニックノイズ）、±10 % のばらつきが差動対の P/N 間不整合となって **50 Hz の CMRR を律速**する | **適用（`R29-1`）。** → **C163508**（Samsung CL10C102JB8NNNC、1 nF 50 V **C0G** ±5 % 0603）。0603 同一フットプリント・同一容量なので銅箔・CPL 不変 |
| **(5)** | `C_NLDO_OUT`（0402、2.2 µF 6.3 V X5R = C12530）は **TPS72325 の −2.5 V 出力コンデンサ**。SLVS346 §8.2.1.1 は出力に **≥ 2.2 µF のセラミック**を要求するが、6.3 V の 0402 に 2.5 V のバイアスがかかると実効容量は **≈50 %** に落ちると見積もられ、最低値を割る | **適用（`R29-2`）。**（→ その後 **Samsung 実測カーブ 25 ℃ で保持率 0.543 = 実効 1.19 µF** と確認。見積もりどおり最低値割れ） → **C23733**（Samsung CL05A475MP5NRNC、4.7 µF 10 V X5R 0402） |
| **(6)** | `C_LM_IN`（0402、1 µF 25 V X5R = C52923）は **LM2664 の V+ 入力コンデンサ**。SNVS005 のテスト回路は **3.3 µF**。1 µF 25 V の 0402 に 5 V を掛けると実効 **≈0.6 µF** | **適用（`R29-3`）。**（→ その後 **Samsung 実測カーブ 25 ℃ で保持率 0.420 = 実効 0.42 µF** と確認。見積もりより**さらに悪く**、テスト回路の 1/8 に満たない） → **C23733**（(5) と同一品番） |
| **(7)** | `R_BIAS_SER` の **1 MΩ 直列**（電極へ）が DRL のループ利得を下げる | **Rev.A 受容。** 患者安全側に保守的な設計であり、そのまま出す。将来 **100〜390 kΩ を並列**に足して利得を上げる選択肢を残す（任意） |
| **(8)** | `R_INx` の **10 kΩ** による熱雑音 ≈ **18 nV/√Hz** は ADS1299 自身の入力換算雑音の **約 2 倍** | **Rev.A 受容。** 電極保護と入力フィルタのための直列抵抗であり、値を下げると保護が弱くなる。火入れの雑音実測を Rev.B の判断材料にする |
| **(9)** | ADS1299 の **GPIO1–4 が GND 直結** | **設計どおり（ECO-1）。ファームウェアは GPIO レジスタ (0x14) を出力に設定してはならない** — 出力 High にすると恒常短絡になる。`reports/bringup_checklist.md` **F3** に記載済み |
| **(10)** | **CHASSIS_GND が GND に対してフローティング**で、`J2` の pin12 が USB シェルに繋がっている | **Rev.A 受容 ＋ 運用規則。運用: `J2` pin12 には何も接続しない**（電極ケーブルを繋がない）。**Rev.B: CHASSIS_GND ↔ GND を 1 MΩ ∥ 4.7 nF で結合する** |
| **(11)** | **AMS1117 の出力がセラミックのみ**（ESR が低く、LDO によっては安定性の余裕が減る）、および **F1 の hold が 0.5 A** | **Rev.A 受容。** Rev.A は **USB-UART のみ**（RF 不使用）で消費は約 **105 mA**、余裕は十分。**Rev.B で Wi-Fi/BLE を使うなら電源設計をやり直す**（送信ピークは数百 mA になり、F1 の 0.5 A hold と AMS1117 のセラミック出力の両方が効いてくる） |
| **(12)** | `C_AVDD_P59`（0402、100 nF = C1525）は **ADS1299 pin59（チャージポンプ用 AVDD）のデカップリング**。SBAS499 §6 は pin59 に **1 µF** を指定 | **適用（`R29-4`）。** → **C52923**（1 µF 0402、既に BOM にある品番）。**リターン側のネットは GND のまま**にした — SBAS499 の推奨に厳密に合わせると銅箔変更になるため、**Rev.B 送り**として記録する |
| **(13)** | **CLKSEL が DVDD に直結**（データシートは **≥ 10 kΩ** 経由を求める） | **Rev.B。** Rev.A は基板を変えない。**ファームウェアは CLK_EN をセットしてはならない**（CLKSEL = 1 のまま CLK_EN を立てると CLK ピンが出力になり、DVDD 直結の経路と衝突する） |
| **(14)** | **SPI の VOH / VIH の余裕が公称ゼロ**（ESP32 と ADS1299 が同じ 3.3 V レールで、規格値どうしを突き合わせると余裕が残らない） | **記録のみ。** 同一レール同士なので実機では問題にならないのが通例。火入れの 7-2（レジスタのライト/リードバック）が実効的な検証になる |
| **(16)** | **LM2664 の V+ 絶対最大が 5.8 V** に対し、USB の上限は **5.5 V**（余裕 0.3 V） | **Rev.B。** 入力に **TVS** を追加する。Rev.A は USB ポート／モバイルバッテリ運用なので受容 |
| **(17)** | **テストポイントが無い** | **Rev.B。** Rev.A は火入れ手順書（`reports/bringup_checklist.md`）で部品パッドを当たる前提 |

> **(15) は本プロジェクトに伝達されていない。** 上表はリードから渡された指摘の全量であり、
> 番号 15 の項目は含まれていなかった。欠番として記録しておく。

---

## 2. レビュアーの見立て（成功確率）

| 条件 | 見立て |
|---|---|
| 2 枚とも動く | **約 70 %** |
| 少なくとも 1 枚は動く | **約 85 %** |
| **ファームウェアを未修正のまま**火入れした場合 | **約 50 %** |

→ **(2) と (9) と (13) のファームウェア必須事項は、基板が届く前に済ませておく。**
数字がいちばん大きく動くのはそこ。

---

## 3. レビュアーが確認できなかったもの（未検証の明示）

| 項目 | 理由 |
|---|---|
| CH340C のデータシート本文 | 配布 PDF が**暗号化**されており本文を読めなかった。(1) の判断は ESP32 側の絶対最大定格と回路トポロジからの推論 |
| MLCC の **DC バイアス特性カーブ** | レビュー時点では取得できず、(3)(5)(6) の「実効容量 ≈○ %」は**見積もり**だった。**→ その後 Samsung の実測カーブ（25 ℃）を入手し、下表のとおり確定した。** ただし**新品番 `C23733`（CL05A475MP5NRNC）の曲線だけは未取得** — 2.5 V / 5 V での実効値は **Samsung weblib で要確認**（公称 2.1 倍・耐圧 6.3→10 V なので改善方向であることは確実だが、数値は未確定） |
| **VCAP1 の実際の DC 電位** | **依然として不明。** SBAS499 の RESET 条件（> 1.1 V）からの推定。実効容量の見積り（60〜65 µF）はこの推定に乗っている。**火入れ 7-3 で実測すること** |
| AMS1117 のデータシート | 配布 PDF が**スキャン画像**で、数値を機械的に読めなかった |
| **JLC ライブラリ側の回転・極性** | JLC の **Component Placement ビューでしか確認できない**。決済後 72 h 以内の "Confirm Parts Placement" で人が見る（手順は `fab/README_発注手順.md` の (4)） |

### 3.1 追補 — Samsung 実測 DC バイアスカーブ（25 ℃、推定ではない）

レビュー後に入手。上表の「見積もり」を置き換える確定値。

| 品番 | 公称 | バイアス | 保持率 | 実効 | 判定 |
|---|---|---|---|---|---|
| `C12530` CL05A225MQ5NSNC | 2.2 µF 6.3 V 0402 | 2.5 V | **0.543** | **1.19 µF** | TPS72325 の要求 2.2 µF に**未達** → (5) の差し替えは妥当 |
| `C52923` CL05A105KA5NQNC | 1 µF 25 V 0402 | 5 V | **0.420** | **0.42 µF** | LM2664 テスト回路 3.3 µF の 1/8 未満 → (6) の差し替えは妥当 |
| `C1525` CL05B104KO5NNNC | 100 nF 16 V 0402 | 2.5 V | **1.026** | 103 nF | 減衰なし。(12) は**容量値そのものの不足**を直す変更であって、減衰対策ではない |
| `C15008` CL31A107MQHNNNE | 100 µF 6.3 V 1206 | 0 V / 1.8 V | **0.91 / 0.648** | **60〜65 µF**（VCAP1 動作点） | TI の 100 µF 指定に対し**不足気味**。ただし効くのは VCAP1 の充電時間が短くなる方向だけで**機能影響なし** → (3) の据え置きはそのまま |
| **`C23733` CL05A475MP5NRNC** | 4.7 µF 10 V 0402 | 2.5 V / 5 V | **未取得** | — | **要確認（Samsung weblib）。** 差し替え後の実効値は未確定。火入れで AVSS リップルを実測して裏を取る |

---

## 4. 反映内容と再生成・検証

### 4.1 BOM の変更（4 件、フットプリント不変・銅箔不変）

| # | designator | 旧 | 新 | ライブラリ / JLC 実装在庫 |
|---|---|---|---|---|
| `R29-1` | `C_CM1P`〜`C_CM8N`（16 個） | `C1588` CL10B102KB8NNNC 1 nF 50 V **X7R** 0603 | **`C163508`** CL10C102JB8NNNC 1 nF 50 V **C0G** ±5 % 0603 | **Extended** / **440,964** |
| `R29-2` | `C_NLDO_OUT` | `C12530` CL05A225MQ5NSNC 2.2 µF 6.3 V X5R 0402 | **`C23733`** CL05A475MP5NRNC 4.7 µF 10 V X5R 0402 | **Basic** / **3,234,528** |
| `R29-3` | `C_LM_IN` | `C52923` CL05A105KA5NQNC 1 µF 25 V X5R 0402 | **`C23733`**（同上） | **Basic** / **3,234,528** |
| `R29-4` | `C_AVDD_P59` | `C1525` CL05B104KO5NNNC 100 nF 0402 | **`C52923`** CL05A105KA5NQNC 1 µF 25 V X5R 0402 | **Basic** / **11,843,732** |
| `R29-5` | `C_VCAP1` | `C15008` 100 µF 6.3 V X5R 1206 | **変更なし** | — |

**Basic に 1 nF C0G の 0603 は存在しない。** JLC の部品検索 API に `componentLibraryType=base` を付けて
`1nF 0603` / `1000pF 0603` / `C0G 0603` を走査した結果、C0G・NP0 のヒットは **0**。
同じクエリ形式で base を付けた `1nF 0603` は現行の `C1588` を返すのでフィルタは機能している。
したがって `R29-1` は Extended になり、**BOM の Extended 行は 13 → 14**（フィーダー費 +$3.07 程度）。

`C163508` の第 2 候補は **`C106246`**（YAGEO CC0603JRNPO9BN102、1 nF 50 V NP0 ±5 % 0603、Extended、在庫 660,254）。
在庫はこちらが多いが、**置換元 `C1588` と同一メーカ・同一 CL10 シリーズ**（誘電体だけが B→C）で
端子形状が同じであることを優先して Samsung を採った。

出典は各エントリの `sources`（LCSC 商品ページ・JLC 部品詳細・TI データシート）。
品番はいずれも **JLC の実装用部品検索 API と LCSC の商品ページの 2 系統**で
パッケージ・誘電体・耐圧・在庫を突き合わせてある。
なおリードの当初候補 `C1611` は **3 nF 50 V X7R 0603** であり、**1 nF C0G ではなかった**（不採用）。

### 4.2 再生成の順序

`19_make_parts_table.py` → `45_apply_eco5_and_bom.py` → `60_export_fab.sh` →
`61_make_bom_cpl.py` → `62_check_fab.py` → `63_gate_s8.py` → `50_final_check.py` → `./run.sh --status`

### 4.3 検証結果

| 検証 | 結果 |
|---|---|
| **基板の差分** | **19 フットプリントの `Value` / `MPN` / `LCSC` プロパティ 57 行のみ。** `.kicad_pcb` の**プロパティ以外の 66,242 行は完全一致**（トラック・ビア・パッド・ゾーン・フットプリント数 141 いずれも不変） |
| **Gerber・ドリル・.gbrjob（14 ファイル）** | **生成日時の行を除いて全ファイル バイト一致。** 除外したのは各ファイルの `G04 Created by KiCad ... date`／`; DRILL file KiCad ... date`／`.gbrjob` の `CreationDate` のみ（1 ファイルにつき 1〜2 行）。**フィールドはプロットされないので当然の結果であり、それを実測で確かめた** |
| ドリルマップ PDF 2 件 | 展開後のページ内容・PDF 骨格とも一致。差は `/CreationDate` のみ |
| **CPL** | **完全一致**（バイト同一。`U_MCU` の 90° オーバーライドも含めて不変） |
| **IPC-D-356**（`fab/board.d356`） | **完全一致** |
| **BOM** | **変更は 4 件ぶんの行のみ**（下記）。30 行 / 133 点は不変 |
| `fab/assembly_top.pdf` | **変わる（正しい）。** F.Fab に Value テキストを刷るので、値の文字列が伸びたぶんだけ描画が変わる。**製造データではなく人が読む図面** |
| `fab/preview_*.png` | 3D レンダの再実行による誤差のみ。**差のある画素は 0.03 %、チャンネル最大差 7/255**（`kicad-cli pcb render` はレイトレースで非決定的）。内容の変化ではない |
| ゲート | **`./run.sh --status` 25 ステップすべて PASS**。S7a 16/16・S8 31/31・**ACCEPTANCE A〜G 40/40**・S7_body 3/3。DRC error 0 / unconnected 0 / 契約パリティ 0 差分 |

BOM の行差分（`fab/BOM_JLCPCB.csv`）:

```
- 100nF   ... C_AVDD_P59 を含む 26 個 ... C1525   qty 26
+ 100nF   ... C_AVDD_P59 が抜けた 25 個 ... C1525  qty 25
- 1nF                C_CM1N..C_CM8P  C0603  C1588    CL10B102KB8NNNC  Samsung  16
+ 1nF 50V C0G 0603   C_CM1N..C_CM8P  C0603  C163508  CL10C102JB8NNNC  Samsung  16
- 1uF     ... C_LM_IN を含む 11 個 ...   C52923  qty 11
+ 1uF     ... C_AVDD_P59 に入れ替わった 11 個 ... C52923  qty 11
- 2.2uF              C_NLDO_OUT           C0402  C12530   CL05A225MQ5NSNC  Samsung   1
+ 4.7uF 10V X5R 0402 C_LM_IN,C_NLDO_OUT   C0402  C23733   CL05A475MP5NRNC  Samsung   2
```

`C12530` は本 BOM で `C_NLDO_OUT` の 1 点だけに使われていたため BOM から消え、
代わりに `C23733` の行が 1 行増える。**総行数は 30 行のまま、総点数も 133 点のまま。**

### 4.4 Rev.B へ送った項目（この文書が正本）

1. **CH340C を 3.3 V 駆動にする**（VCC = 3.3 V、V3 を VCC に接続）— 指摘 (1)
2. **`C_AVDD_P59` のリターンを GND → AVSS**（銅箔変更）— 指摘 (12)
3. **CHASSIS_GND ↔ GND を 1 MΩ ∥ 4.7 nF** で結合 — 指摘 (10)
4. **CLKSEL を ≥ 10 kΩ 経由で DVDD へ** — 指摘 (13)
5. **LM2664 の V+ に TVS** — 指摘 (16)
6. **テストポイントを置く** — 指摘 (17)
7. **Wi-Fi/BLE を使うなら電源設計をやり直す**（F1 の hold、AMS1117 の出力段）— 指摘 (11)
8. `C_VCAP1` の誘電体 — 指摘 (3)。火入れの実測を見てから判断
9. `R_BIAS_SER` に 100〜390 kΩ 並列（任意）— 指摘 (7)

### 4.5 Rev.A の運用規則

- **`J2` の pin12（SHLD）には何も接続しない** — 指摘 (10)
- **ファームウェアで `MISC1 = 0x00`、tPOR（128 ms）後に RESET パルス** — 指摘 (2)
- **ADS1299 の GPIO レジスタ (0x14) を出力にしない** — 指摘 (9)
- **CLK_EN をセットしない** — 指摘 (13)
- 火入れで **U0RXD のアイドル電圧**（`reports/bringup_checklist.md` 5-5）と
  **VCAP1 の立ち上がり**（同 7-3）を実測する

---

## 追記 2026-08-29: R29-6 ベース抵抗 470 kΩ 化、シミュレーション前後の数値

指摘 (1)（CH340C の 5 V 駆動）のうち **ESP32 の EN / IO0 側だけ**を、
Rev.A のまま BOM のみで是正した。銅箔・CPL・Gerber は不変。
発見元は headless ngspice ハーネス（`sim/cases/esp32_autoreset.py`、`gates/S3_sim.json`）。

### 何が起きていたか

CH340C は `U_USB` pin16 VCC = `USB_5V` で動くため DTR#/RTS# は 5 V スイングする。
両ハンドシェイクが H（アイドル＝通常実行状態）のとき、OFF 側トランジスタは
ベース 5 V・コレクタ 3.3 V となり **B-C 接合が順バイアス**され、コレクタから
`ESP_EN` / `ESP_IO0`（いずれも 10 kΩ プルアップ）へ電流が注入される。

### 変更

| designator | 旧 | 新 |
|---|---|---|
| `R_Q_EN_B`, `R_Q_IO0_B` | `C25804` 10 kΩ 0603 | **`C23178`** 470 kΩ ±1% 0603（UNI-ROYAL `0603WAF4703T5E`・**JLC Basic**・在庫 1,256,032） |

同一メーカ・同一 `0603WAF` シリーズ・同一 `R0603` ランドなので基板側は
Value / MPN / LCSC の 3 フィールド × 2 部品のみが変わる。

### シミュレーション実測（ngspice 45.2、25 ℃、S8050 汎用 Gummel-Poon フィット）

| 項目 | 10 kΩ（従来） | 100 kΩ（当初案・不採用） | **470 kΩ（採用）** | 限界 |
|---|---|---|---|---|
| アイドル `ESP_EN` | 4.238 V | 3.687 V | **3.414 V** | 3.600 V |
| アイドル `ESP_IO0` | 4.203 V | 3.640 V | **3.398 V** | 3.600 V |
| `ESP_EN` への注入電流 | 93.85 µA | 38.71 µA | **11.40 µA** | — |
| 真理値表 ON 側（EN / IO0） | 0.010 / 0.011 V | 0.032 / 0.035 V | **0.066 / 0.072 V** | ≤ 0.4 V |
| 真理値表 OFF 側（EN / IO0） | 3.297 / 3.300 V | 3.297 / 3.300 V | **3.297 / 3.300 V** | ≥ 2.6 V |
| 判定 | **NG** | **NG** | **OK** | |

真理値表は 4 状態とも esptool の ClassicReset どおり（`HH→H,H` / `HL→L,H` / `LH→H,L` / `LL→H,H`）。

### なぜ 100 kΩ では足りなかったか（当初案を却下した理由）

「抵抗 10 倍 → 注入 1/10」という見積りは OFF 側をダイオードとみなしたもので誤り。
実際は**逆活性領域**（B-C 順バイアス・B-E 逆バイアス）にあり、
コレクタ注入電流は**ベース電流の (1+BR) ≈ 5 倍に増幅**される
（実測 Ib 7.63 µA → 注入 38.71 µA、比 5.07 対 モデル BR=4）。
さらに R を上げると節点電圧が下がって R 両端の電圧が増えるため自己制限がかかり、
10 k→100 k で電流は **2.4 倍しか下がらない**（93.85 → 38.71 µA）。

実測スイープ: 10 k 4.238 / 22 k 4.086 / 47 k 3.890 / 100 k 3.687 / 150 k 3.593 /
220 k 3.518 / 330 k 3.456 / **470 k 3.414** / 1 M 3.356 V。
真理値表は 1 MΩ まで成立し、2.2 MΩ で破綻（IO0 の ON 側が 0.533 V）。

### 470 kΩ を選んだ根拠（モデル感度）

判定は S8050 の**逆方向電流増幅率 BR** に依存する。BR は S8050 データシートに記載がなく、
汎用 Gummel-Poon フィット値（BR=4）にすぎない。BR を 1〜10 で振った感度解析:

| R | BR=1 | BR=4 | BR=10 | 全域で 3.6 V 以内か |
|---|---|---|---|---|
| 100 k | 3.497 | 3.687 | 3.898 | **否**（BR≤2 のみ） |
| 220 k | 3.399 | 3.518 | 3.686 | 否（BR≥7 で失敗） |
| 330 k | 3.367 | 3.456 | 3.592 | 可（ただし余裕 8 mV） |
| **470 k** | 3.347 | 3.414 | **3.523** | **可（最悪余裕 77 mV）** |
| 1 M | 3.321 | 3.356 | 3.417 | 可（余裕 183 mV） |

1 MΩ はさらに安全だが、**ベース駆動余裕**を優先して 470 kΩ を採った。
5 V ハンドシェイク時の ON 側ベース電流は実測 **9.33 µA**、
S8050 J3Y の hFE 下限 200 で **Ic 能力 1.87 mA**（フィット値 BF=275 なら 2.57 mA）。
必要なシンク電流はプルアップ 10 kΩ の 0.33 mA のみで 5 倍以上の余裕がある。
`C_EN_DLY`（DC バイアス減衰後 0.62 µF）を 3.3 V から 0.4 V 以下へ放電するのに要する時間は
Ic = 1.87 mA で約 1.0 ms、1.8 mA としても **≈1.6 ms** で、
esptool が RESET を保持する 100 ms に対して十分短い。

### EN 立ち上がり遅延の合否基準を差し替えた

従来の基準「EN は 3.3 V レールの **10 ms 以上あと**に立ち上がること」は
**どのデータシートにも無い数値**だった。Espressif の要求は
「電源が安定するまで EN を Low に保つこと」であり、
ESP32-WROOM-32E/32UE データシートは 10 kΩ / 1 µF の RC を**その手段として推奨**しているだけで
最小遅延時間を規定していない。基準を **「レール整定後に EN が解放されること」**に改めた。

実測: 3.3 V レールが 99 % に達するのが **0.30 ms**、EN が VIH に達するのが **8.84 ms**
（**8.54 ms 後・レール整定時間の 29 倍**、DC バイアス減衰後の 0.62 µF での値）。
公称 1 µF なら 14.12 ms。旧基準では減衰後の値が 8.55 ms で「不合格」、
公称値が 13.85 ms で「合格」になっていたが、これは**発明した閾値の副産物**であって欠陥ではない。

### ゲート

`gates/S3_sim.json` は **27/29 → 29/29 pass**。
（絶対最大の項目が実測で解消、EN 遅延の項目は基準を正しいものに差し替えて合格。
遅延の数値そのものは引き続きゲートに記録される。）

### この変更で直っていないこと

- **`U_USB` pin2 TXD → `ESP_RXD`（`U_MCU` pin34）の 5 V 直結は未対処**。
  こちらは漏れ電流ではなく**駆動されたプッシュプル出力**なので、抵抗値では抑えられない。
  R29-6 は無関係。**Rev.B 項目（下記 4.4 の 1 番）のまま。**
- 注入自体が消えたわけではない。470 kΩ でも `ESP_EN` は 3.3 V レールを 0.11 V 上回る
  （絶対最大内に収めただけ）。**火入れで EN / IO0 の実電圧を測ること。**
- 根本策は **CH340C を 3.3 V 駆動にすること**（VCC = 3.3 V・V3 を VCC に接続）で、
  これは銅箔変更のため Rev.A では不可。実施すれば EN/IO0 の注入と TXD 経路が同時に解消する。

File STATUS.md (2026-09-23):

# STATUS — brain_canvas_kicad

最終更新: 2026-09-23 / 担当: S0–S2 → S3・S4 → S5・S6 → S7・S8 → S9 → L7〜L9・H・S8 再出力・S9 再投入 → 独立機能レビュー反映（BOM のみ 4 件・銅箔不変） → S3_sim（ngspice）＋ R29-6 反映（BOM のみ 1 件・銅箔不変） → **S7v（via-in-pad の是正）・基準 I 追加・S8 再出力（Y9）** → **S7p（ステンシル開口のはみ出し 168 個）・S7d（行き先のない配線 33 本・via 5 本）・基準 J / K・裁定 3 件の記録・S8 再出力** → **S9 再投入（Y9 → JLC 品目 Y13）**

> ## ▶ 現在地（2026-09-23 23:44）: Y9 をカートに投入済み（JLC の品目番号は Y13）。決済なし。Y8 の 2 品目は施主の了承（「1 OK」）を受けてカートから削除した
>
> | 品目 | 番号 | 金額 | Y8 との差 |
> |---|---|---|---|
> | PCB（4 層・1.6 mm・Green・ENIG・JLC パネル化 1×1／四辺 12.5 mm・5 パネル） | `Y13-10641515A` | $47.15 | +$1.15（うち Confirm Production file の +$1.05） |
> | Standard PCBA（Top・2 パネル・Confirm Parts Placement = Yes） | `SMT026092362927-10641515A` | $218.48 | −$10.26 |
> | 合計（送料別） | | **$265.63** | −$9.11（Y8 は $274.74） |
>
> - **Via Covering は Plugged になった。** JLC が Tented を選べなくし、無料で Plugged に置き換えていた（"The Via Tented option is upgraded to Via Plugged for free."）。lead 裁定で受け入れた。
>   Plugged はソルダーマスクのインクを穴に詰めるだけで、充填・キャップではない。そのため基準 I（SMD 開口の via 0 本）はそのまま効く。
>   IPC-4761 のどの Type に当たるかは、JLC の公式ページに記述がないので **unverified** とした。
>   `product.yaml` の `fab.via.covering`、`data/order_spec.json`、ACCEPTANCE の追記 3 を合わせて直した。
>   ハーネスの S7_viapad は、この宣言でも **16/16** が緑（`gates/harness_S7_viapad.json`。covering は Plugged と記録され、0 本かどうかで判定されている）。
> - **BOM**: 31 行を検出し 31 行とも確定、在庫不足 0、C 番号は repo と差 0。JLC が U_USB に自動で当てた C7464026 は C84681 に戻した。"multiple types" の 12 行は手でチェックした。
> - **配置**: C_VCAP3・C_VCAP3_H・C_VCAP4・C_VREFP_10n の位置と向き、U_ADS・U_MCU・J1 の 1 番ピンを、盤面ファイルのパッド座標と CPL に突き合わせた。すべて一致した。
>   J1 は、1 番ピンの点に加えて pad12（GND）側にも JLC の点が出るが、本体の向きは正しい。
> - 記録: `gates/S9.json`（Y8 の記録は `y8_record` と history に残した）、スクショ 12 枚は `fab/jlc_cart_2026-09-23_y9/`。
> - Y8 の 2 品目（`Y8-10641515A` / `SMT026082960311`）はカートから削除済み（スクショ 12）。M5 と Ganglion の品目には触っていない。
> - **次（施主）**: Y13 の 2 行だけを決済する。
>   決済後は、JLC の Confirm Production file に 48 h 以内、Confirm Parts Placement に 72 h 以内に応答する。

> ## ✅ 2026-09-24: 新しい afe-adc J1 でも緑（lead 裁定 (a)）。DVDD 48/50 の配線の長さは Rev.B の候補（(b)、J1 の外）
>
> - ハーネス cyton-3a（`ca429f1`、Q508 でベタ免除を「経路がベタを通るとき」に限った版）の J1 を HEAD の盤面に当てた。**pass 0**。判定したのは 100 行で、宣言済みの例外 1 件（C_VCAP1 → pin 28）が効いている。stale 0。
> - ピンごとの実測（4 層 JLC04161H-7628）は次のとおり。AVDD 21/22 は C_AVDD_P31 まで F.Cu で 2.9〜3.9 mm、via 0。AVDD 19/56/59 は、ピンから 1.5〜2 mm の F 配線で via に入り、In2 の AVDD ベタ（281 mm²）に落ちる。TI SBAS499C Fig.80（p.73）と同じ「電源はベタで配る」作りなので、免除は正当。
> - **別件（(b)、Rev.B の候補）**: DVDD 48/50 は via 0 だが、最寄りの C_DVDD_P40 まで F.Cu で **10.6〜13.7 mm**（直線距離では 6.2〜8.3 mm）ある。経路の L の見積もりは 3〜14 nH で、m5stack パターン 2 の DVDD（J1 で赤）と同程度。J1 は via の本数しか数えないので緑になる。Rev.B では、**全電源ピンについて via 0・2 mm 以内に 100 nF を 1 個**置く（m5stack と同じ必須項目）。
> - 物理的な判断の要旨: fMOD = 1.024 MHz で、100 nF のリアクタンス 1.55 Ω に対し経路は 0.02〜0.09 Ω。ADC 自身の電流は fCLK 同期なので DC に畳まれる。入力換算ノイズへの影響は無いと判断した（MHz 帯の PSRR は DS に数値が無いので、推測を含む）。**火入れで確かめる**: `reports/bringup_checklist.md` の 8-5。
> - 盤面・fab・BOM/CPL・`gates/S9.json` は不変。Y13 の決済は止めない。

> ## ✅ 2026-09-24: ハーネス S5_netconstraints の赤 4 件（C2〜C5）は実害なしと裁定した。Y13 の決済は止めない
>
> - 経緯: ハーネス 225f76c で S5_netconstraints（afe-adc C1〜C5）が初めて判定され（Q535）、1/5 だった。独立に評価した結果、**lead 裁定で 4 件とも実害なし**とした。詳細は ACCEPTANCE 追記 8。
> - 4 件とも **Y8（c444ac2^）からあった形**で、Y9 の修正で増えたものはない。S7v で via の位置が変わり、C2 は 5 本から 4 本に減った。
>
> | 件 | 実測（HEAD） | 要旨 |
> |---|---|---|
> | C2 | VCAP1 の via 3 本、VCAP3 の via 1 本 | VCAP1 の 3 本は J1 の例外にした C_VCAP1 の枝と同じもの。VCAP3 の 1 本は追加の C_VCAP3_H の枝にあり、DS が求める C_VCAP3 は F.Cu・via なし |
> | C3 | VCAP1 の同じ枝の B.Cu（6 区間） | C2 と同じ事実 |
> | C4 | IN1N〜IN8N に via 2 本ずつ（16 本） | P と N の容量差は推定 1.5 pF 以下で、50 Hz で −107 dB。C_CM の ±5% の差（−76 dB）と R_IN の 1% の差（−90 dB）より 17〜31 dB 小さい |
> | C5 | ch1〜ch4 の長さの差 1.877 mm | 上限 1.0 mm は pack の既定値。約 12 ps で、1 kHz の位相は 7e-8 rad。HackEEG は 2〜4 mm |
>
> - **宣言した**: C2 だけ。`product.yaml` の `packs.afe-adc.c2_accepted_exceptions` に 4 件を書いた（座標で指定、許容差 0.05 mm、帰属つき）。
> - **再判定**（harness 225f76c）: 1/5 → **2/5**（C1・C2 が緑、C3・C4・C5 は赤のまま）。
> - **C3・C4・C5 は製品側に宣言の仕組みがない**。ハーネス側に必要な仕組みを ACCEPTANCE 追記 8 に書き、core-b に回した。
>   - C3/C4 の例外キー
>   - C5 の上限を pack で宣言するキー（製品は 2.0 mm を入れる予定）
>   - `skew_source` の誤記
>   - 負の対照が走っていない
>   仕組みができるまでは、裁定済みの既知の赤として扱う。
> - **出典**
>   - TI SBAS499C https://www.ti.com/lit/ds/symlink/ads1299.pdf の p.9（CMRR −110 dB（最小）、バイアス電流 ±300 pA）、p.68（§10.2 差動 C、C_CM は C_DIF の 1/10〜1/20）、p.70（§11 VCAP1）、p.72（§12.1 "Do not place vias between bypass capacitors and the active device"）
>   - HackEEG の実測: `pcb-harness/fixtures/hackeeg_ref`
>   - via の値は Howard Johnson の近似式による推定
> - **Rev.B の候補**
>   - C_CM*N/P の配置を見直し、IN*N を F.Cu だけで通す
>   - C_VCAP3_H をピン 55 と F.Cu で直結する

> ## ⛔ 2026-09-23: Y8 は via-in-pad 106 本のため決済不可。修正版 Y9 の fab を用意済み。カートの差し替えは lead が行う
>
> **Y8（PCB `Y8-10641515A` ＋ PCBA `SMT026082960311`）は決済しないこと。** Y8 の盤面では
> **via 106 本のドリルが SMD パッドのソルダーマスク開口の中に開いていた**（Gerber 実測。
> ハーネス S7_viapad の盤面センサスでは 112 本）。発注は Tented の 4 層で via を塞ぐ工程がないため、
> リフロー時にはんだが穴へ流れ込む。影響するのは 0402 の 29 か所（via 外径 0.61 mm がパッドより大きい）、
> ADS1299 の TQFP ピン 44、入力 CM コンデンサ 16 個、ESP32 のランドなど。
> A〜H にこれを見る項目がなかった。ECO-5 のときに 1 本だけ手で外していた（下の「ECO-5」節）。
>
> **是正（S7v、`scripts/66_fix_via_in_pad.py`）**: 開口に近い via 116 本（配置用の余裕 0.03 mm で数えた場合）を処理した。
> 114 本をパッドの外へ出して短い配線（dogbone）でつなぎ、どこにもつながっていない
> AVSS via 2 本（C_VREFP_10n / C_VREFP_100n。In2 の AVDD ベタの中にある 0.5 mm の AVSS 島だけに乗っていた）は取り除いた。
> via の穴埋め（有料 POFV）には頼らず、Via Covering は **Tented のまま**。
> どうしても抜けなかった 2 か所は、隣の配線を動かして場所を空けた（`ROOM_EDITS`）。
> - U_MCU.16: ESP_RXD の内側の脚を 0.629 mm 西へずらした。
> - D_ESD.3: ESP_RXD / ESP_TXD をパッド列の間で北へ寄せ、0.1524 mm に細くした。ESP_RXD の via も 0.381 mm 北へ移した。
>
> | 項目 | Y8 | **Y9** |
> |---|---|---|
> | SMD 開口にかかる via（Gerber、`gates/S7_viapad.json`） | 106（F.Paste を含めると 111） | **0**（最小間隔 0.0327 mm） |
> | 同（ハーネス S7_viapad の盤面センサス） | 112 | **0**（ハーネスの fab 側の判定も pass） |
> | via 数 | 241 | **234**（S7v で −2、S7d で −5） |
> | DRC error / 未接続 | 0 / 0 | **0 / 0** |
> | DRC の track_dangling / via_dangling | 26 / 3 | **0 / 0**（S7d、基準 K） |
> | パッドの外に出るステンシル開口（Gerber、`gates/S7_paste.json`） | 168（最大 0.134 mm） | **0**（S7p、基準 J） |
> | 契約パリティ（ネットリスト） | 0 差分 | **0 差分** |
> | IN1P〜IN8N の ADC〜入力抵抗の経路長 | — | **変化 0.000 mm**、P/N の長さ差も 8 対すべて不変 |
> | SRB1 の経路長 | — | +0.9 mm（全長 40.8 mm）。**lead 裁定で受け入れ、上限 1.0 mm を ACCEPTANCE に固定** |
> | VCAP1 | — | ピン 28 → C_VCAP1_H のパッドは 1.358 mm で**不変**。伸びたのはバルク側（C_VCAP1 100 µF）だけで 12.665 → 16.548 mm。AVSS に戻るループ面積は 4.282 → 4.277 mm² / 14.723 → 14.730 mm² で悪化なし。**lead 裁定で受け入れ** |
> | CM コンデンサの GND via | — | パッドから 1.3〜1.9 mm。**lead 裁定で受け入れ** |
> | BOM / CPL | — | BOM は**不変**（`740b7ef7…`）。CPL は **C_VREFP_10n の 1 行だけ**変わった（Y −110.480 → −110.580、S7j `23a6080`。sha256 `f46e2d6e…`）。部品・回転はすべて不変 |
>
> ゲートは S7v 8/8・S7p 3/3・S7d 5/5・S7b・S7c・S8 31/31・S7 40/40・S7_body・**S7_viapad（基準 I）7/7・S7_paste（基準 J）4/4**
> がすべて pass（`./run.sh --from S7v`、S7v より前の盤面から通しで実行）。
> ACCEPTANCE.md の「追記 3」に基準 I と裁定を、「追記 4」に基準 J / K を加えた。
>
> **新しい fab**: `fab/Therapia_EEG-HRV_Rev.A.zip`（sha256 `429ad5f3…`）、
> `fab/board.d356`、`fab/CPL_JLCPCB.csv`、`fab/BOM_JLCPCB.csv`（BOM は Y8 と同じ内容。CPL は C_VREFP_10n の 1 行だけ違う。最終の sha256 は zip `00dd48f4…`・BOM `740b7ef7…`・CPL `f46e2d6e…`、HEAD `8a89179`）。
> **次（lead）**: カートの Y8 の 2 品目を削除し、この zip を再アップロードして Y9 にする。
> BOM / CPL は同じ設定（31 行、Standard、Confirm Parts Placement = Yes）で入れる。
> 決済・DFM / Confirm Parts Placement への応答は施主。

> ### 2026-09-23: ハーネスの安全ゲート 5 本（harness main `093191b`）に Y9 を当てた。宣言だけを追加し、盤面・fab・gates/ は変えていない
>
> | ゲート | 追加前 | 追加後 | 残った赤 |
> |---|---|---|---|
> | S6（DRC、read-only） | 14/16 | 15/16 | `npth_holes`: ハーネス側の欠陥（Q477。穴表を契約座標として読む）。DRC は clean、短絡 0 |
> | S7（最終集約） | 28/58 | 54/58 | ① D NPTH（board）: Q477 と同じ座標系の問題（ずれが 182 mm）。発注データ側の行は pass ② F の panel 行 ③ F の DNP 一致行: 製品の `logs/bom_cpl.json` にハーネスが読む `pcba_type` / `dnp.agree` 節がない（書式の差。製品ログの `dnp_agree` は True）④ K: `gates/S7_clearance.json` がない（ハーネスの S7_clearance は 8/8 だが、出力を gates/ に置かない方針） |
> | S8（発注パッケージ） | 42/52 | 50/52 | S7 の ② ③ と同じ |
> | S7_viapad | 16/16 | 16/16 | — |
> | S7_clearance | 6/7 | 8/8 | — |
>
> **盤面の欠陥は 0 件。** 足した宣言は次のとおり。
> - `product.yaml`: `board.pth_pads` 16、`board.thickness_mm` 1.6、`fab.order_spec`、`fab.human_facing`（iso プレビューはない）、
>   `fab.pcba_side` Top、`packs.jlcpcb.pcba_type_required` Standard PCBA、`paths.dnp` / `paths.mech_contract`、
>   `nets.netless_copper`（契約で NC の 34 ピン、Q478）、`gates.S7`（ACCEPTANCE C の数値、5 mil 推奨を warning に置く `clearance`、規則生成器）、
>   `gates.S8`（部品数 135 / DNP 2 / 実装 133 / テストポイント 0）
> - 新規ファイル: `data/dnp.json`、`data/order_spec.json`（カートの内容。Tented = IPC-4761 Type I と記載）、`contract/mech_contract.json`（切り欠きなし）
> - `contract/netlist_contract.json`: `mechanical_parts`（H1〜H4、PEG1/2）を追加。**`scripts/20_netlist_contract.py` で再生成すると消える**
> - ハーネスの出力は `$TMPDIR` に置いた。検証は製品のコピーで行った
>
> **追記（同日、残りの赤を閉じた）** 結果は S0_manifest **50/50**、S7 **57/58**（残るのは ① D NPTH の盤面座標の行で、ハーネス側の Q477 として vip-root に回した）、
> S8 **52/52**、S7_viapad 16/16、S7_clearance 8/8。
> - ②③ `scripts/61_make_bom_cpl.py` が、`logs/bom_cpl.json` にハーネスの書式で `dnp` 節（data/dnp.json・部品表・盤面の三者一致）と `pcba_type` 節を書くようにした。
>   実装区分の証拠は `data/pcba_type.json` に部品番号ごとに置いた。31 行すべて "Standard"。
>   証拠は gates/S9.json で、Standard PCBA の注文 SMT026082960311 が全 31 行を受け付けている（rows_confirmed 31/31）。そのときの BOM は現在と同じ sha256 `740b7ef7…`。
>   Economic でも実装できるかは記録がないので、主張していない。"unknown" の行は 0。
>   再生成後も `fab/BOM_JLCPCB.csv`（`740b7ef7…`）と `fab/CPL_JLCPCB.csv`（`1ea6f984…`）はバイト単位で変わっていない。
> - ④ ハーネスの S7_body / S7_viapad / S7_clearance（harness commit **093191b**）の出力を、名前がぶつからないように
>   `gates/harness_S7_body.json`・`gates/harness_S7_viapad.json`・`gates/harness_S7_clearance.json` として置いた。
>   既存の `gates/S7_body.json` と `gates/S7_viapad.json` は、この repo の基準 H・I のゲートなので上書きしていない。
>   S7 はこの 3 つを `gates.S7.subgates` の宣言で読む。**盤面を保存し直すと鮮度切れで赤になる**ので、そのときは 3 本とも再実行すること。
> - afe-adc pack の必須キー **20 個**（S0_manifest の表示は先頭 8 個で切れていた）を、契約・製品スクリプト・DS の引用から宣言した。
>   `vcap1_min_uf` 100（DS のピン表）、`vrefp_bulk_min_uf` 10、`bad_dielectric` は DS §11 の [X5R, X7R, X8R] に Y5V / Z5U を加えたもの。
>   実物の C_VCAP1 は CL31A107MQHNNNE（X5R 100 µF）。DS §11（p.70）は「多くの場合 VCAP1 も MLCC」としていて、
>   X5R などの強誘電体を避けるのは**振動がある系に限った推奨**（圧電ノイズのため）。**lead 裁定（2026-09-23）: 部品は替えない。**
>   ADS1299EVM と OpenBCI Cyton も X5R 100 µF を使っている。1.2 V での実効容量は約 90 µF（最悪 72 µF）、帯域は約 0.2 Hz で、DS の要求（10 Hz 未満）を満たす。
>   この裁定は product.yaml に `packs.afe-adc.vcap1_dielectric_ruling`（ハーネス Q490 の書式: vibration / reason / approved_by / date）として記録した。
>   振動の影響は火入れで実測する（`reports/bringup_checklist.md` の 7-3）。

> ### 2026-09-23: 独立 QA（SHIP、BLOCKER 0・MAJOR 0）の MINOR を盤面で直し、fab を出し直した
>
> | MINOR | 何を直したか | 結果 |
> |---|---|---|
> | 1 | S7v の配置余裕を 0.03 → **0.10 mm** に上げ（4 段階とも）、基準 I に「ドリル端〜SMD 開口 0.10 mm 以上」を追加した。行き場のない 4 か所は `ROOM_EDITS` で個別に直した: **U_MCU.16**（ADS_PWDN_N を B.Cu で ADS_DRDY_N / ADS_RESET_N の間の通路に通し、U_MCU.14 の via はパッドの内側端へ移動）、**C_LM_FLY.1**（B.Cu に 2 via で渡っていた区間を F.Cu の直線にした）、**FB4.2**（VNEG5 の B.Cu を 0.358 mm 南へ振って via の場所を作った）、**R_CC2.2**（部品の下、パッドの間に 0.46/0.30 mm の via） | Gerber で測ったドリル端〜開口の最小距離 **0.1007 mm**（前回 0.0327）。0.10 未満は 0 本 |
> | 2 | S7m（`scripts/71_mask_webs.py`）: 異ネットのパッド 22 組について、関係する 35 パッドのマスク拡張だけを下げた。値は (銅の間隔 − 0.10) / 2 で、全体の 0.0508 はそのまま。**基準 L**（`scripts/72_mask_web_gate.py`、Gerber、陰性対照つき） | 異ネットで堤が 0.10 未満の組は **0**。物理的に無理な組も 0。同ネットの 17 組は触っていない（`logs/mask_webs.json`） |
> | 5 | D_ESD.3 のパッド内にあった F.Cu 0.45 mm の切れ端を削除した | — |
> | 4 | S3_sim の期待チェック数を 29 に固定し、足りなければ赤にした。TI モデルの失敗やタイムアウトも行を省かず赤として書く | 今回は **30/30**（29 ＋ 件数の確認行）。途中の 1 回は LM2664 の TI モデルが ngspice の既知の起動時の不具合（`.func pwr`）で 8 回再試行しても失敗し、**正しく赤になった** |
>
> - **全ゲート**: S7a・S7p・S7v 8/8・S7d・S7m・S7b・S7c・S8 31/31・S7 40/40・S7_body・S7_viapad 8/8・S7_paste・**S7_maskweb**・S3_sim 30/30。
>   ハーネス（main `0c78e9b`）でも S0_manifest 50/50・S6 **16/16**・S7 **58/58**・S8 52/52・S7_body 4/4・S7_viapad 16/16・S7_clearance 8/8 がすべて緑（Q477 はハーネス側で解消済み）。
>   ハーネスの出力は `gates/harness_S7_*.json` として置き直した。
> - **DRC**: error 0 / 未接続 0 / dangling 0。warning は clearance 5（5 mil の推奨値。前と同じ）、courtyard 63、silk 系 356、starved_thermal 1。
>   **ネットの同一性**: 契約パリティ 0、全パッドのネットは不変。
>   **アナログ経路**: IN1P〜IN8N の ADC〜入力抵抗の経路長の変化は最大 0.0013 mm（via の位置で配線がわずかに曲がった分）。P/N の長さ差の増加も最大 0.0013 mm。SRB1 は +0.7 mm。
> - **via 数** 241 → **232**。内訳は、S7v で機能のない via −2、C_LM_FLY の B.Cu 経由 −2、S7d で片側だけの via −5。
> - **新しい fab**: zip `f926c3b8…`、`board.d356` `7bddec12…`。BOM（`740b7ef7…`）と CPL（`1ea6f984…`）は変わっていない。
> - afe-adc pack の S5_layout を当てると、J3/J4/J6/J7/J10 は pass（J4 は VCAP1 の裁定の記録で pass）。**J1（バイパスコンデンサと ADS のピンの間の via）3 件は赤**。これは既存の設計で、製品側の S7c が「報告のみ」で数えているものと同じ（今回の依頼の範囲外）。

> ### 2026-09-23: afe-adc の J1（バイパスコンデンサと ADS のピンの間に via）と S3_sim の不安定を直した
>
> **J1**（S7j、`scripts/73_bypass_caps.py`）:
>
> | 部品（ピン） | 対処 | ピン→コンデンサ（前 → 後） | via | AVSS に戻るループ面積 | インダクタンスの目安 |
> |---|---|---|---|---|---|
> | C_VCAP4 1 µF（26） | ピン 26 の真下へ移動（C_VCAP1_H と同じ向き）。パッド 1 はピンの既存の F.Cu に乗り、パッド 2 は F.Cu の AVSS 配線（y 109.769）に乗る | 9.213 → **1.358 mm** | 2 → **0** | 18.60 → **6.40 mm²** | 約 7 → 約 0.7 nH |
> | C_VCAP3 1 µF（55） | C_VCAP3_H（100 nF）と位置を交換。同じ 0402 でパッドのネットも同じなので、銅は動かしていない | 5.190 → **2.100 mm** | 2 → **0** | 4.02 → **2.14 mm²** | 約 5 → 約 1 nH |
> | C_VCAP1 100 µF（28） | **動かしていない**（F.Cu だけで結ぶ経路が物理的にない。下記） | 12.665 → 16.548 mm | 4（うち C_VCAP1_H 側の 2 本は変わらない） | 14.72 → 14.73 mm² | — |
>
> インダクタンスは、0.2〜0.25 mm の配線を内層の面から約 0.2 mm 上に通したときの目安 0.5 nH/mm と、1.6 mm 厚を貫く via 1 本あたり約 1.3 nH で見積もった粗い値。
> `product.yaml` の `packs.afe-adc.ds_required_cap` に、DS が求める容量のコンデンサ（VCAP1: C_VCAP1、VCAP3: C_VCAP3、VCAP4: C_VCAP4、VREFP: C_VREFP_10u）を宣言した。
> ハーネスの afe-adc S5_layout の J1 は **3 件 → 1 件（C_VCAP1）**。
>
> **C_VCAP1 を F.Cu だけで結べない理由（数値）**:
> - ピン 28 の周り: 隣のピン 27 / 29 まで 0.22 mm。真下の C_VCAP1_H まで 0.208 mm、C_VCAP1_H と C_VCAP2 の間は 0.314 mm。
>   異ネットの間に 0.2 mm の配線を 1 本通すには 0.378 mm 要るので、どれも通れない。
> - その南側: 同じ F.Cu を AVSS の配線（y 109.769、x 146.92〜151.29）と VREFP の配線（y 111.496、x 145.92〜151.75）が、クラスタの幅いっぱいに横切っている。
> - 1206（本体 3.2 × 1.6 mm）をピン 28 の近くに置く場所がない。置くには C_VCAP1_H・C_VCAP2・C_VREFP_100n・C_VREFP_10u を並べ替える必要がある。
> - C_VCAP1_H（100 nF）はピン 28 から F.Cu で 1.358 mm、via なしのまま。
> - **lead 裁定（2026-09-23）: J1 の宣言された例外として受け入れた**（`packs.afe-adc.j1_accepted_exceptions`。理由は ACCEPTANCE の追記 6）。
>   ハーネス 1e232da（Q492）で J1 がこの宣言を読むようになり、**afe-adc S5_layout は 4/4**（C_VCAP1 は「宣言された例外」として通る）。
>
> **S3_sim**:
> - 原因: TI のモデルを読むために PSpice 互換モード（`ngbehavior=psa`）を使っていた。このモードでは ngspice 45.2 がデッキの先頭に自前の補助関数（`.func pwr` など）を差し込み、その解釈にときどき失敗していた。
> - 対処: TI のモデルを ngspice ネイティブの書き方に機械変換した写しを使い、互換モードは使わない（`sim/lib/pspice_native.py`。TI の原本はそのまま）。
>   VSWITCH は ngspice 自身の互換モードと同じ `pswitch` に写した（libngspice の変換テンプレートから読んだもの）。
>   元の互換モードでの実行と比べて、LM2664 の出力電圧・リップル、TPS72325 の出力電圧（EN あり / EN = 0 V）は **5 桁まで一致**。
> - 再試行は既定で 1 回（再試行しない）にした。10 回連続で **10/10 回とも 30/30**。
> - あわせて、実行ごとの一時ディレクトリが消されずにディスクを埋めていた不具合を直した。
>
> **ゲート**: 製品側は全て pass。ハーネス（0c78e9b）は S0_manifest 50/50・S6 16/16・S7 58/58・S8 52/52・S7_body 4/4・S7_viapad 16/16・S7_clearance 8/8。
> - DRC: error 0 / 未接続 0 / dangling 0。courtyard と silk の warning は部品移動の分だけ増えた。
> - via-in-pad の最小距離 0.1007 mm、異ネットのマスク堤 0.10 mm 未満は 0、ペーストのはみ出し 0。
> - IN1P〜IN8N の経路長の変化は最大 0.0013 mm。via は 230 本。
> - 新しい fab: zip `14304d82…`、`board.d356` `2fa13efe…`。**CPL は 3 行変わった**（C_VCAP3 / C_VCAP3_H / C_VCAP4、`2c68a8ef…`）。BOM は変わっていない。

> ### 2026-09-23: 再 QA（SHIP）の MINOR の最後の仕上げ
>
> | MINOR | 何をしたか | 結果 |
> |---|---|---|
> | 1（マスク堤が 0.09998 mm、13 組） | S7m の設計目標を **0.105 mm** に上げた。基準 L は 0.10 mm のまま判定し、別の行で 0.105 の設計目標も判定する | 異ネットで 0.105 未満は **0 組** |
> | 3（新しく足した銅が他ネットまで 0.092 mm） | S7v の配置で他ネットまで 0.127 mm を守らない段（0.10 / 0.0889 mm）を廃止した。固定の編集（`ROOM_EDITS`）も 0.127 mm で検証する。**D_ESD.3**: UART の 2 本をパッド列の間だけ 0.1016 mm に細くして北へ寄せた。**J1.4（USB_CC1）**: 0.46/0.30 mm の via に替えた。新しい検査 **S7n**（`scripts/74_new_copper_clearance.py`）で、今回足した配線・via・パッドを全部測る | 0.127 mm 未満は 2 件だけで、どちらも理由を記録した例外: **R_CC2.2 の via 0.120 mm**（パッド間 0.70 mm に入る最大。0.127 mm にするには via 径 0.446 mm が要るが、ドリル 0.30 mm で環幅 0.076 mm を守る最小径は 0.452 mm）、**ADS_RESET_N の幹線 0.1018 mm**（Y8 の銅を短くしただけで、この距離は取り込み時からのもの） |
> | 2（C_VCAP4 が詰まっている） | C_VCAP4 はピン 26 の下のまま（F.Cu 1.358 mm、via なし）。C_VREFP_10n を 0.10 mm 南へずらした。C_VCAP4 を上へ動かすとピン 26 まで 0.208 → 0.118 mm になり、回すと C_VCAP1_H まで 0.06 mm になるため | C_VCAP4.2 と C_VREFP_10n.2 のパッド間は 0.114 → **0.214 mm**、マスク開口は分かれた（堤 0.112 mm）。courtyard の干渉 4 件は残った: EasyEDA の 0402 の courtyard（1.93 × 1.17 mm）はピッチ 1.0 mm の並びでは必ず重なる。部品本体どうしの隙間は 0.35〜1.75 mm で、基準 H も pass |
> | 4 | STATUS の数字を 17 組に直した（上の表） | — |
>
> - **ゲート**: 製品側は全て pass（S7n を含む）。ハーネス 1e232da は S0 50/50・S6 16/16・S7 58/58・S8 52/52・S7_* すべて緑・**afe-adc S5_layout 4/4**。
>   DRC は error 0 / 未接続 0 / dangling 0。IN1P〜IN8N の経路長の変化は最大 0.0013 mm、via は 230 本、via-in-pad の最小距離 0.1007 mm。
> - **新しい fab**: zip `00dd48f4…`、`board.d356` `dcc35c27…`、CPL `f46e2d6e…`（前回から C_VREFP_10n の 1 行だけ変わった）。BOM は変わっていない。

## 現在地

**S0〜S9 完了。** ただし下の記録は Y8（2026-08-29）時点のもので、**Y8 は上のとおり決済不可**。`gates/S9.json`。

| | |
|---|---|
| カート | https://cart.jlcpcb.com/shopcart/cart |
| PCB | `Y8-10641515A` — 4 層 / 1.6 mm / Green / ENIG / **JLC パネル化 1×1・四辺 12.5 mm レール（86.82×70.01 mm）** / **5 パネル** / 3 日 / **$46.00** |
| PCBA | `SMT026082960311-10641515A` — **Standard** / Top 片面 / **2 パネル** / 5〜6 日 / **$228.74**（部品 $141.97・フィーダー $45.90・段取り $25.56・ステンシル $8.21 ほか）/ Confirm Parts Placement = Yes（自動確認しない） |
| 合計 | **$274.74 ＋送料**（同カートの Ganglion 2 品目は触っていない） |

> **2026-08-29 13:09 に Y7 → Y8 へ更新**: R29-6（ESP32 自動リセットのベース抵抗 `R_Q_EN_B`/`R_Q_IO0_B` を 10 k → **470 kΩ**）。
> ngspice ハーネス（`sim/`、`gates/S3_sim.json` 29/29 pass）が CH340C 5 V 動作による EN/IO0 の
> 待機電圧 4.24 V（絶対最大 3.6 V 超）を検出 → 100 kΩ では 3.69 V で不足（逆活性領域で (1+BR)≈5 倍）、
> 470 kΩ で 3.41 V・真理値表維持。BOM 31 行 / 133 点、銅箔・CPL 不変（commit `0faeed7`）。
> **2026-08-29 12:12 に Y6 → Y7 へ更新**（カートの「Edit Order」で同じ Gerber のまま BOM を入れ直した）。
> 第三者視点の機能レビュー（`reports/functional_review_2026-08-29.md`、BLOCKER 0）が勧めた無料の BOM 改善 4 件:
> 入力 1 nF ×16 を X7R → **C0G**（C163508）、`C_NLDO_OUT`/`C_LM_IN` を **4.7 µF/10 V**（C23733、Samsung 実測曲線で
> 実効容量 2.5 倍）、`C_AVDD_P59` を 1 µF。銅箔・CPL は不変（`data/bom_fixes_2026-08-28.json` R29-1〜5、commit `eba012d`）。

> ### ✅ 2026-08-29 13:09: BOM 5 件の変更はカート（Y8）に反映済み — 決済してよい
>
> 独立機能レビュー（`reports/functional_review_2026-08-29.md`）の指摘 4 件と、
> ngspice シミュレーション（`gates/S3_sim.json`）が見つけた 1 件を反映して
> **BOM だけ** 5 件変更した。**Gerber・CPL・IPC-D-356 は生成日時の行を除いて前回と完全一致。**
> カートの「Edit Order」で BOM を入れ直し、**カートの 31 行と repo の BOM（commit `0faeed7`）が一致することを確認済み**。
>
> | designator | 旧 | 新 |
> |---|---|---|
> | `C_CM1P`〜`C_CM8N`（16） | `C1588` 1nF X7R 0603 | **`C163508`** 1nF 50V **C0G** 0603（Extended・在庫 440,964） |
> | `C_NLDO_OUT` | `C12530` 2.2µF 6.3V 0402 | **`C23733`** 4.7µF 10V 0402（Basic・在庫 3,234,218） |
> | `C_LM_IN` | `C52923` 1µF 25V 0402 | **`C23733`**（同上） |
> | `C_AVDD_P59` | `C1525` 100nF 0402 | **`C52923`** 1µF 0402（Basic・既に BOM にある品番） |
> | **`R_Q_EN_B`, `R_Q_IO0_B`（2）** | `C25804` 10kΩ 0603 | **`C23178`** 470kΩ 0603（**Basic**・在庫 1,256,032） |
>
> **総行数 30 → 31 行、総点数 133 点は不変。Extended は 13 行 → 14 行**（フィーダー費 +$3.07）。
> `C12530` は BOM から消える。`C25804` は残るが員数が 9 → 7 に減る。
> 理由・出典は `data/bom_fixes_2026-08-28.json` の `R29-1`〜`R29-6`。
>
> **`R29-6` の理由**: CH340C が `USB_5V` で動くため DTR#/RTS# が 5V スイングし、
> アイドル時に OFF 側トランジスタの B-C 接合が順バイアスされて `ESP_EN`/`ESP_IO0` へ
> 電流が注入される。ngspice 実測で **`ESP_EN` 4.24V / `ESP_IO0` 4.20V**（ESP32 の絶対最大 3.6V 超）。
> ベース抵抗を 470kΩ にすると **3.414V / 3.398V** に収まり、リセット真理値表は維持される
> （ON ≤0.072V / OFF ≥3.297V）。当初案の 100kΩ は 3.687V で**不合格**だった
> （逆活性領域でコレクタ注入がベース電流の (1+BR)≈5 倍に増幅されるため）。
> **`C25804` 10kΩ に戻さないこと。** 詳細は `reports/functional_review_2026-08-29.md` の「追記 2026-08-29」。

> **18:46 に入れた最初の品目（Y5 / SMT026082861630）は 21:12 に削除した。** JLC の配置プレビューで
> ユーザーが ESP32 と ADS1299 の重なりに気づき、実測したら本物だった（下記「発注を止めた 2 件」）。
> 直した基板（commit `1c8a769`）を再アップロードしたのが Y6。

### 発注を止めた 2 件（DRC は通っていた）

| # | 何が | 実寸 | 直し |
|---|---|---|---|
| L8 | **ESP32-WROOM-32E の本体（25.5 mm、−X 端 6.3 mm はアンテナ keep-out）が ADS1299 のパッケージに乗っていた** | 本体どうし **−2.81 mm**、ADS の右ピン列 16 本と 0402 3 個（C_AVDD1_100n / C_AVDD1_10n / C_DVDD_P40）が真下 | 部品を **ESP32-WROOM-32UE-N4（C701344）** に差替。ランドパターンは同一（Espressif DS 明記）で銅箔不変、本体 19.2×18 → ADS 本体まで **+3.77 mm**、真下ゼロ。外形シルク/コートヤードを描き直し、**CPL の回転を 0→90**（JLC の 32UE フットプリントは 90° 向きが違う。`data/cpl_overrides.json`）。Rev.A は USB-UART のみで RF 不使用 → アンテナ無しで可（Espressif: RF を初期化しなければ RF ピンはオープン可） |
| L7 | **R_CC1（0603）が USB-C レセプタクルのシェル底板の真下** | シェル外形 x 175.79..181.87 の内側、前面から 4.6〜5.4 mm 奥（メーカー図面: シェル底は連続板、逃げ無し） | R_CC1 を (173.400, 113.900) rot 180 へ 6.5 mm 移動、USB_CC1 は B.Cu 経由で再配線（via +2）。J1 本体から 1.21 mm クリア |

**なぜ DRC で止まらなかったか**: `courtyards_overlap` を ACCEPTANCE A で warning に落としていた
（「EasyEDA 由来のコートヤードは実寸より大きく、配置は 8/16 版と同じ」— だが 8/16 版は一度も製造されていない）。
→ **基準 H を追加**: `scripts/64_body_overlap.py` が部品本体（F.Fab の図形）どうしの重なりを実寸で判定し、
許容リスト `data/body_overlap_allow.json`（AMS1117×H4、J1×自分のペグ穴）以外は fail。修理前の基板に当てると
J1×R_CC1 と U_ADS×U_MCU を名指しする。`./run.sh --status` は 25 ステップ全 pass。

Economic ではなく **Standard** なのは、`U_MCU`（ESP32-WROOM-32E, C701341）が JLC で
「Standard Only」だったため。基板 61.8×45 は Standard 単板の最小 70×70 未満なので
**JLC 側のパネル化**で寸法を満たした（ユーザー指示: 手はんだはしない、全部実装してもらう）。

カート投入時に JLC 実装在庫 0 だった 2 点を差し替えた（正本 `data/bom_fixes_2026-08-28.json`、
BOM/parts table は再生成済み・Gerber は不変）:

| 部品 | 旧 | 新 | 根拠 |
|---|---|---|---|
| `D_LED` | C72044（Everlight 赤、**廃番・在庫 0**） | **C84268** NCD0603Y1（NationStar 黄） | EasyEDA パッケージ名 `LED0603-RD` が同一実体、生ピンデータ pin1=K で基板の pad1=GND=カソードと一致。在庫 605,820。**CPL 回転変更なし** |
| `F1` | C369159（在庫 0） | **C43379** SMD1206P050TF/13.2（RUILON） | 0.5 A hold / 1 A trip / 13.2 V の定格が旧品と同一、F1206 同一パッド。在庫 19,984 |

`U_USB` は JLC の自動照合が C7464026（WCH CH340C の別リスティング）に当てていたので
repo BOM と同じ **C84681** に戻した（在庫 62,653）。**30 行すべて repo BOM と一致**。

配置プレビュー（Component Placements）で極性部品の pin 1 を KiCad のパッド座標
（`pcbnew` で dx/dy/net をダンプ）と突合し、**11 種すべて一致**:
AMS1117 / D_ESD / D_LED（− 左 + 右）/ LM2664 / Q_EN・Q_IO0 / TLV70025 / TPS72325 /
U_ADS（pin1 左上）/ U_USB（pin1 左下）/ U_MCU（アンテナ側＝パッド無し側が左）/ J1。

**次にやること（人）**: ①決済 ②JLC の DFM 指摘と Confirm Parts Placement に 72 h 以内に応答
③到着後 `reports/bringup_checklist.md` で火入れ（MISC1=0x00、tPOR 後に RESET パルス）。

| | |
|---|---|
| DRC | error **0** / unconnected **0** / warning 470（全て ACCEPTANCE A の許容種別） |
| 契約パリティ | **0 差分**（`contract_overrides.json` の ECO-5 を適用した契約に対して） |
| 部品 | 141 = 実装 133 ＋ DNP 2 ＋ 機械 6 |
| 製造データ | Gerber 14 ファイル / BOM **31 行** 133 点 / CPL 133 行 / IPC-D-356 678 features |
| 3 系統照合 | ネット数 **79 = 79 = 79**（Gerber X2 / IPC-D-356 / ODB++、契約とも一致） |
| 8 月版との照合 | 129 部品中 **122 が位置・回転とも完全一致**、動いた 7 点は全て記録済みの判断 |

### S7・S8 で見つけて直した、発注を止めていた欠陥

**スルーホール部品のレジストが表裏とも開いていなかった。** 取り込みで PTH/NPTH
パッド 22 個すべてが「銅箔層だけ」のレイヤ構成になっており（F.Mask も B.Mask も無い）、
そのまま出すと **`J2` の 12 ピンヘッダ全部と `J1` の USB-C シェル脚 4 本が
両面レジストで覆われ、はんだ付けできない基板**になっていた。
DRC は何も言わない（開口を要求していないパッドは違反ではない）。
`scripts/43_fix_pth_mask.py` で修正。詳細は下記 S8 の節。

| ステップ | 結果 | 内容 |
|---|---|---|
| S0 | **pass** 12/12 | kicad-cli 10.0.5 / KiCad python 3.9.13 / `pcbnew` / `EASYEDAPRO` / `ZONE_FILLER` / `drc --refill-zones` 全て有り |
| S1 | **pass** 4/4 | `ProPrj_Therapia_EEG-HRV_2026-08-28_v2.epro`（227,363 B, sha256 `83c096a6c23aa482…`）を `import/` へ確保 |
| S1B | **pass** 6/6 | `.epro2` も同時に確保されていたため変換も実施（`*.converted.epro`）。ただし**正規の旧 `.epro` があるのでそちらを採用**。変換物は使っていない |
| S2 | **pass** 17/17 | 取り込み・パッド網補修・突合すべて一致 |
| S2B | **pass** 5/5 | 回路図ネットリスト（EasyEDA API 由来）を契約として取り込み、PCB との差分＝ECO-1 の残作業を列挙 |
| S4a | **pass** 10/10 | NPTH 6 穴を合成、基板外形を閉じた（`scripts/13_fix_import.py`） |
| S3 | **pass** 10/10 | ACCEPTANCE.md 凍結、JLC ルール生成、DRC ベースラインで L1〜L4 を検出（`14_make_rules.py` / `15_gate_s3.py`） |
| S4 | **pass** 10/10 | ECO-1/2/3 を PCB へ適用（`19_make_parts_table.py` / `20_apply_eco.py`） |
| S5_uuids | **pass** 3/3 | 重複 KIID 2,625 個を採番し直した（`26_fix_uuids.py`）。**これを先にやらないと DRC が違う部品を指す** |
| S5_L1 | **pass** 8/8 | AMS1117 を H4 から退避（`30_repair_L1.py`） |
| S5_L2 | **pass** 6/6 | CHASSIS_GND を H1 の東へ迂回（`31_repair_L2.py`） |
| S5_L3 | **pass** 6/6 | ESP_TXD を分割して中央だけ H4 から逃がす（`32_repair_L3.py`） |
| S5_L4 | **pass** 7/7 | USB-C ペグ穴 PEG1/PEG2 を完全に空けた（`33_repair_L4.py`） |
| S5_L5 | **pass** 7/7 | 残り 27 箇所の近接を解消（`34_repair_L5.py`） |
| S5_mask | **pass** 2/2 | レジスト開口の合体 3 件をパッド個別マージンで解消（`35_mask_bridges.py`） |
| S6 | **pass** 11/11 | DRC 自動ループが `clean` で停止（`40_drc_loop.py` / `41_drc_fix_pass.py`） |
| S7a | **pass** 16/16 | ECO-5（銅箔 1 パッド）＋ BOM 修正 8 件 ＋ DNP 2 点（`45_apply_eco5_and_bom.py`） |
| S7b | **pass** 5/5 | アナログ信号路が 1 件も動いていないことを実証（`46_analog_untouched.py`） |
| S7c | **pass** 6/6 | ADS1299 チェックリストで実測・VCAP3 のビアを 2 個除去（`47_layout_quality.py` / `48_improve_vcap3.py`） |
| S8 | **pass** 30/30 | 製造データ出力と独立検査（`60_export_fab.sh` 〜 `63_gate_s8.py`）。Gerber X2 / IPC-D-356 / ODB++ の 3 系統で照合 |
| S7 | **pass** 40/40 | **ACCEPTANCE A〜G**（`50_final_check.py`） |

`./run.sh --status` でいつでも同じ表が出る。**DRC を含むステップはサンドボックス外で実行すること。**

`run.sh` の実行順は S8 → S7。ACCEPTANCE の D〜G は S8 が出力した製造データを読むので、
先に出力しないと最終ゲートが検査対象を持たない。

### 最終 DRC（`logs/drc_final.json`、S7d 実行時）

```
violations 470   error 0   warning 470   unconnected 0
warning 内訳: silk_overlap 199 / silk_over_copper 157 / courtyards_overlap 77 /
              track_dangling 26 / clearance 5 / via_dangling 3 /
              silk_edge_clearance 2 / starved_thermal 1
```

S6 時点（465 件）との差は S7・S8 の変更ぶんだけで、**error は一貫して 0、
新規の error 署名も 0**: `silk_over_copper` +5 は PTH のレジスト開口を直したことで
シルクの下の銅が露出したため、`track_dangling` +1 は `C_VCAP3_H` を移した際に
共有 AVSS 島に残した短いスタブ、`courtyards_overlap` −1 は同じ移動の副産物。

**warning はすべて ACCEPTANCE A の許容リストに載っている種別だけ。**
`clearance` の 5 件は error ではなく、ACCEPTANCE C が warning と定めた
「推奨 5 mil (0.127 mm)」に対するもの（error 級の 0.0889 mm は 0 件）。
**Amendments は不要だった** — solder_mask_bridge は 8 件とも実際に直せたので、
ACCEPTANCE.md には一切手を入れていない。

### 実行順が S4a → S3 → S4 になっている理由

S3 のゲートは「設計ルールが L1〜L4 を実際に検出すること」を検定する。取り込み直後は
取付穴が NPTH ではなく PTH パッドなので、hole clearance ルールに引っかかる穴が 1 つも無く、
L1 / L2 / L4 が原理的に検出できない。だから NPTH 合成（S4a）を先に済ませる。

### S2 の実測（EasyEDA ↔ KiCad 完全一致）

| 項目 | 値 |
|---|---|
| 部品 | 131（designator 集合も一致。重複なし） |
| フットプリント総数 | 135 = 131 ＋ M2 取付パッド 4（EasyEDA の基板直置きパッドは designator を持たないので KiCad が無名フットプリントに包む） |
| パッド | 429（うちネット有り 385 / 無ネット 44 ＝ 部品内 40 ＋ M2 4） |
| ネット | 77（員数も全ネット一致。**#19021 のネット融合なし**） |
| トラック | 1191（層別一致。ARC は 0） |
| ビア | 238 |
| ベタ（POUR） | 10（In1=GND / In2 に AVDD・USB_5V×2・VDD_ESP×3・AVSS ほか） |
| 銅箔層数 | 4 |
| 外形 | 61.8235 × 45.0090 mm（規定 61.8236 × 45.0088、Edge.Cuts 中心線基準） |
| 回転 | {0:79, 90:40, 180:4, 270:8} ⊆ {0,90,180,270}、CPL と全一致 |
| 穴 | 22/22 一致（M2 φ2.3876 ×4、J2 φ1.05 ×12、J1 スロット ×4、USB-C ペグ φ0.700 ×2） |
| 原点移動 | KiCad が (120, 80) mm 平行移動 |

`fab_2026-08-16` の CPL（131 部品）と位置・回転・パッド1座標が**全件一致**したので、
この export は 2026-08-16 の製造パッケージと同じ幾何。

## S3 / S4 でやったこと

### S4a — 取り込み欠陥の修理（`scripts/13_fix_import.py`）

| 症状 | 対処 |
|---|---|
| M2 取付穴 ×4 が PTH パッド | `H1`〜`H4` の NPTH（φ2.3876、銅なし、BOM/POS 除外）へ |
| USB-C ペグ ×2 が J1 の Edge.Cuts 多角形 | 独立フットプリント `PEG1`/`PEG2` の NPTH（φ0.700024）へ。J1 の多角形は削除 |
| **基板外形が 3 本の開いた線分**（新発見） | EasyEDA は外形を閉じた `POLY` 1 本（`0,0 → 2434,0 → 2434,-1772 → 0,-1772` mil）で持っているのに、KiCad のインポータが**閉じる 1 本を落としていた**。取り込み時 DRC の `invalid_outline` 1 件の正体。矩形 4 本を厳密寸法で引き直した |

ゲート: NPTH 6 穴が `fab_2026-08-16` の旧 DRL と **±2µm 一致**、PTH 16・via 238 不変、Edge.Cuts 4 本。

### S3 — 受け入れ基準とルールの凍結

- `ACCEPTANCE.md`（発注可の定義 A〜G）。**以後変更しない**。最終ゲートの仕様そのもの
- `scripts/14_make_rules.py` が `.kicad_pro` / `.kicad_dru` / `.kicad_pcb` の `(setup)` を生成（冪等）
- **DRC は 1025 件 → 526 件（error 67〜69）に落ちた。** 前は KiCad 既定ルールに対する数字だったので
  意味が無かった。`invalid_outline` `track_width` `annular_width` `padstack` `shorting_items`
  `copper_edge_clearance` `lib_footprint_issues` は全て消えた
- **ゲートは「ルールが L1〜L4 を実際に検出すること」を検定する**。4 件とも実測 0.0000 mm で検出:

| | 検出内容 | 実測 |
|---|---|---|
| L1 | H4 ↔ AMS1117 pad1 (GND) | hole clearance **0.0000 mm** |
| L2 | H1 ↔ CHASSIS_GND の Bottom 配線 | **0.0000 mm** |
| L3 | H4 ↔ ESP_TXD の Bottom 配線 | **0.0000 mm** |
| L4 | PEG2 ↔ USB_VBUS_RAW トラック 6 本＋via 8 本 / PEG1 ↔ via 4 本 | hole clearance **0.0000**、hole-to-hole **0.0000**（ECO の「via バレル不成立」と一致） |

### S4 — ECO-1 / ECO-2 / ECO-3 の適用（`scripts/20_apply_eco.py`）

**ネット変更 8 ピン、全部入った**（致命バグ B1 を含む）:

| designator | pad | → | 結線方法 |
|---|---|---|---|
| TPS72325 | 3 (EN) | `V_NLDO_IN` | pin2 (IN) へ直線 0.95 mm ＝ **B1 解消** |
| U_ADS | 31 (RESV1) | `GND` | AVDD スタブ除去 → pad33 (GND) へ L 字 |
| U_ADS | 42/44/45/46 (GPIO1–4) | `GND` | 42→pad41、44/46→45 で同辺に束ね |
| U_ADS | 30 / 55 (VCAP2/VCAP3) | 新ネット | コンデンサ側で結線（下記） |

**新設 4 部品・全部配置**（`C0402` を実寸複製、値/MPN/LCSC 付き）:

| designator | 位置 [mm] | 回転 | 対象ピンからの距離 | pin1 経路 |
|---|---|---|---|---|
| C_VCAP2 | (149.166, 109.172) | 0° | 1.53 mm | 直線 |
| C_VCAP3 | (144.118, 94.262) | 90° | 3.36 mm | via ホップ |
| C_VCAP3_H | (141.832, 95.024) | 270° | 5.44 mm | L 字（VCAP3 へ 2.29 mm） |
| C_VCAP1_H | (147.912, 109.426) | 270° | 1.36 mm | 直線 |

**ECO-3 の 1206 化・両方成功**（**90° 回転が鍵**。元の向きでは物理的に入らない）:

| designator | 位置 [mm] | 回転 | 移動量 |
|---|---|---|---|
| C_VCAP1 | (152.258, 115.052) | 90° | 2.50 mm |
| C_VREFP_10u | (150.937, 110.226) | 90° | 0.57 mm |

**ECO-2** は値と LCSC のみ（フットプリント不変）。**135 部品全部**に Value / MPN / `LCSC` フィールドを設定
（`data/parts_lcsc.csv` が正、`scripts/19_make_parts_table.py` が生成）。

結果: 部品 137→**141**（135 実装部品 ＋ 機械 6）、トラック 1191→1213、via 238→240。
**PCB 全パッドの net map ＝ 契約（差分 0）**、**未接続 0**、DRC error は**ベースラインから増えていない**。

## S5 — L1〜L5 のレイアウト修理

DRC error の推移: **S4 後 67〜69 → L1 59 → L2 57 → L3 56 → L4 30 →
（KIID 修正）28 → L5 4 → mask 1 → S6 0**。
unconnected は全工程を通じて 0、契約パリティも全工程 0 差分。

### 修理の一覧（座標はすべて KiCad mm）

| | 対象 | やったこと | 実測 |
|---|---|---|---|
| **L1** | H4 (176.9468, 121.9608) φ2.3876 が AMS1117 pin1(GND) を貫通 | AMS1117 を **+3.25 / +1.25 mm**（東・南）へ移設。原点 (173.594, 119.9795) → **(176.844, 121.2295)**。GND スタブ 3 本と GND via (175.372, 122.418) を撤去し、pin1 は新しい via で GND 面へ落とした。pin2/3/4 は既存銅に接続したまま | 全パッドの穴縁間 **0.4335 mm**（規則 0.2） |
| **L2** | H1 (123.048, 83.048) を CHASSIS_GND の Bottom 配線が貫通 | J2/12 (123.556, 87.2645) → (124.064, 81.016) を **H1 の東 x≈124.6505 まで膨らませて 4 セグメントで引き直し**（6.43 mm、直線なら 5.84 mm） | 0.3 mm 以上 |
| **L3** | H4 に ESP_TXD の Bottom 配線が 0.076 mm 食い込み | 11.68 mm の配線を**3 本に分割**し、(178.4755, 120.7415)〜(175.4181, 120.7415) の中央だけ 3 セグメントで引き直し | 0.3 mm 以上 |
| **L4** | PEG1 (176.8611, 113.8779) / PEG2 (176.8611, 108.0979) φ0.7 | PEG1 は via 退避＋配線 4 本の迂回。**PEG2 は経路そのものを廃止**（下記）。J1 の pin1/pin12 は 0.05 mm/片側 詰めた | 両穴とも**リング内の銅ゼロ**、J1 パッド 0.1712 → **0.2211 mm** |
| **L5** | 残り 27 箇所の近接 | via 退避 14・配線分割迂回 9・部品微動 4 | すべて 0.0889 mm 以上 |
| **mask** | レジスト開口の合体 3 件 | 該当 5 パッドのマージンを 0.0508 → 0.0307 / 0.0418 mm | web 0.0508 mm ＋2 µm 確保 |

### L4 の PEG2 は「近接」ではなく「経路の問題」だった

ECO は原因を「Slot Region e54/e55」としているが、実体は EasyEDA layer 12 の
FILL 円 **id e36 / e37**（S4a が NPTH パッド化済み）。ECO の id は当てにせず、
**基板の実形状から取り直した**。実測:

```
PEG2  via [USB_VBUS_RAW] (177.2010, 108.1430)  銅 -0.3119  穴間 -0.1596
      USB_VBUS_RAW トラック 6 本  -0.1086 〜 -0.3711
PEG1  via [USB_VBUS_RAW] (176.6930, 113.2230)  銅 +0.0213  穴間 +0.1736
```

via のドリルとペグのドリルが 0.16 mm 重なる＝**バレルが成立せず VBUS が基板に来ない**
（ECO の指摘どおり）。しかし PEG2 側は退避では直らなかった:
VBUS が J1 pin11 に届く唯一の経路が、ペグと裏面 ESP_RXD の間を東へ抜ける通路で、
**その通路の銅がすべてペグのリング内にある**。トラックは両端がリング内なので
「自分の両端の間を引き直す」では動かせず、via は 2.5 mm 以内に合法な置き場所が無い。
→ **その 7 本（トラック 6・via 1）を削除し、J1 pin11 を西側から給電**した
（2.03 mm。VBUS の via が 2.4 mm 西に既にあり、もう一方の VBUS パッド pin2 は
もともと西から来ている）。

### J1 pin1 / pin12 のパッドを 0.05 mm 詰めた（フットプリント変更）

USB-C コネクタの**自分の GND パッドが自分のペグ穴から 0.5213 mm** しか離れておらず、
穴縁間 0.1712 mm ＝ 規則 0.2 mm に **0.0288 mm 足りない**。これは配線ミスではなく
ベンダのフットプリント形状。基準を緩めるのではなく、
**ペグ側の軸に 0.05 mm/片側 詰めた**（ランド長 1.10 → 1.00 mm、−9%）。
USB-C の機械的保持は PTH のシェル脚 pad13/14 が担っており、pin1/12 は信号 GND なので
接合強度に実害はない。`gates/S5_L4.json` の `pad_trims` に前後の寸法と隙間を記録。

### 部品の微動（L5）

| designator | 移動 |
|---|---|
| C_AVSS_B | +0.15 mm (x) |
| C_3V3_H | +0.05 mm (y) |
| C_VREFP_10n | +0.05 mm (x) |
| C_RST_DLY | −0.05 mm (x) |

いずれも 0402。どちらもパッド同士の近接で、動かせる銅が他に無かった箇所。

### レジスト開口（solder_mask_bridge）— 8 件すべて実際に直した

`ACCEPTANCE.md` は**一文字も変えていない**。Amendments 節も作っていない。
S4 時点の 8 件のうち 5 件は L1〜L5 の銅の移動で自然に消え、残り 3 件は
パッド個別の `solder_mask_margin` を下げて解決した:

| ペア | 銅の隙間 | マージン |
|---|---|---|
| C_VCAP1_H/2 (AVSS) ↔ C_VREFP_100n/1 (VREFP) | 0.1142 mm | 0.0508 → 0.0307 |
| Q_IO0/3 (ESP_IO0) ↔ R_Q_EN_B/2 (Q_EN_B) | 0.1364 mm | 0.0508 → 0.0418 |
| Q_IO0/3 (ESP_IO0) ↔ R_Q_EN_B/1 (CH_DTR_N) | 0.1364 mm | 0.0508 → 0.0418 |

板全体の `pad_to_mask_clearance`（ACCEPTANCE C の 0.0508 mm）は不変。
レジストをパッドの内側に食い込ませてもいない（下限は 0）。

## S6 — DRC 自動ループ

`scripts/40_drc_loop.py`（ドライバ・素の python3）＋
`scripts/41_drc_fix_pass.py`（1 反復ぶんの修正・KPY）。
**pcbnew は 1 プロセスで 2 回 LoadBoard できない**ので、DRC を回す側と基板を触る側は
必ず別プロセスにする。停止条件は 4 つ（`clean` / 20 反復 / 2 連続で解決ゼロ /
違反集合ハッシュの再出現）。**件数では判定しない**（同一基板でも 525〜531 と揺れる）。

初回は `stalled` で止まり、それが**修正器の本当の穴を炙り出した**:
最後の 1 件は ADS_RESET_N が C_RST_DLY の自分の GND パッドから 0.0685 mm の位置で
西へ折れる**トラックの端点そのもの**にあった。端点が違反なのだから、
同じ両端の間を引き直しても直らない。加えて部品微動は「成功」と報告していたが、
その合法性検査は**自部品のパッドと自部品に付いた配線を無視する**ので、
まさに問題のペアを見ていなかった。`retreat_track_end`（角と、そこに集まる配線を
まとめて動かす）を足し、微動には実際のペアの隙間を検証させた。次の実行で 1 反復で解決。

### 人が見るべき点（施主向け・DRC は通っている）

1. **AMS1117 が 3.48 mm 動き、その本体が H4 の真上に来た。**
   西・北（ECO が指定した向き）は塞がっている ── 西は pad4 が FB3 pin2 と U_USB pin8 に、
   北は pad3 が J1 pin13（USB-C シェル）と PEG1 に当たる。空いているのは南東の隅だけ。
   **移設前から本体は H4 の西半分を覆っていた**が、移設後は穴全体を覆う。
   H4 に M2 のネジ頭やスペーサが来る設計なら干渉する。**筐体側の確認が要る。**
   （探索は「本体が穴に掛からない位置」を最優先で走査したが、±8 mm に 1 つも無かった）
2. **J1 pin1 / pin12 のランドが 1.10 → 1.00 mm。** 上記のとおり。
3. **C_VCAP3 の pin1 が 3.36 mm、C_VCAP3_H が 2.29 mm**（S4 から未変更）。
   バイパスコンデンサとしては長い。ADS1299 北側は AVDD/AVSS の逃げ配線で埋まっている
4. **C_VCAP1 が 2.50 mm 移動**（S4、1206 化のため）。ADS1299 のレイアウト指針に照らして要確認
5. **旧 STATUS の「3 点目」は事実として二重に誤っていた。施主にそのまま報告しないこと。**
   旧記載は「C_VCAP1_H が C_AVSS_P37 とレジスト開口を共有（両方 AVSS で短絡し得ない）」。
   - **相手が違う。** S4 時点の DRC レポート（`logs/drc_after_eco.json` /
     `logs/drc_S5_before.json`）に C_AVSS_P37 という組み合わせは 1 件も無い。
     当時の記載は `C_VCAP1_H/2 [AVSS] ↔ C_3V3_H/1 [VDD_ESP]`。しかもこれ自体、
     重複 KIID による誤同定だった（この 2 パッドは実際には 9.3 mm 離れている）
   - **同ネットではない。** KIID 修正後に実体を取り直すと相手は **C_VREFP_100n/1 [VREFP]**。
     AVSS ↔ VREFP の**異ネット**で、隙間 0.1142 mm。短絡し得る本物の欠陥だった
   - 履歴上のどの DRC レポートにも**真に同ネットのレジスト開口共有は 1 件も無い**
     （`lib/drc.harmless()` は一度も発動していない）。「同ネットだから非欠陥」という
     整理は、この基板では使う場面が無かった
   - 対処は上表のとおりパッド個別マージンの縮小。**非欠陥として分類したのではなく、直した**

## 設計上の発見（取り込みの不具合ではない）

`gates/design_observations.json` に機械可読な形で置いてある。

### ECO-1 は PCB に未適用（確定）— 残作業の全量

回路図（ECO-1 適用済み）と PCB（未適用）の差分を機械的に取った結果が
`gates/netlist_diff.json`。**これが S3 の作業指示そのもの**。

**追加すべき部品 4 個**: `C_VCAP1_H` / `C_VCAP2` / `C_VCAP3` / `C_VCAP3_H`
（いずれも 2 ピン、片側 `AVSS`）。新規ネット `VCAP2` / `VCAP3` も PCB 側に存在しない。

**ネットを変更すべきピン 8 本**:

| designator | pin | pin name | 回路図（正） | 現 PCB |
|---|---|---|---|---|
| TPS72325 | 3 | EN | `V_NLDO_IN` | **`GND`** ← 致命バグ B1 が残存 |
| U_ADS | 31 | RESV1 | `GND` | `AVDD` |
| U_ADS | 42 | GPIO1 | `GND` | 未結線 |
| U_ADS | 44 | GPIO2 | `GND` | 未結線 |
| U_ADS | 45 | GPIO3 | `GND` | 未結線 |
| U_ADS | 46 | GPIO4 | `GND` | 未結線 |
| U_ADS | 30 | VCAP2 | `VCAP2` | 未結線 |
| U_ADS | 55 | VCAP3 | `VCAP3` | 未結線 |

ECO-1 の表（項目 1〜5）と完全に対応する。`AVDD` のパッド数 21 も
`PROJECT_STATUS.md` の「ECO 前 21・ECO 後 20」と整合。

KiCad 側には回路図が無いので、**S3 はこの 8 本＋4 部品を PCB 上で手作業で再現する**ことになる。

**expected_delta の数え方について**: lead の想定は「20 ピン差＋新設 4 部品 8 パッド」だが、
現 PCB との実差分は **16**（既存ピンのネット変更 8 ＋ 新設 4 部品のパッド 8）。
ECO 文書の「全ピン diff = 意図した 20 件」は**回路図の変更前後**の差分で、
④リネーム（`C_3V3_B`/`C_3V3_H` 系 2 部品 ×2 ピン = 4 件）を含む。
リネームは PCB 側に既に反映済み（`C_3V3_B` と `C_3V3_B2`、`C_3V3_H` と `C_3V3_H2` が
回路図・PCB の双方に別部品として存在し、ネットも一致）。よって PCB に対する残作業は 16 で正しい。

### FB5 — **決着済み（2026-08-28、lead 判断）。PCB 側の変更は不要**

**FB5 pin1 = `VDD_ESP` / pin2 = `DVDD`。契約どおりで、これが設計の正。**

S2 は「3.3V 系の VDD_ESP と 2.5V 系の DVDD をフェライトで直結しているように見える」と疑義を出したが、
**前提が古かった。DVDD は 3.3V 給電が正**（ADS1299 の DVDD 範囲 1.8〜3.6V 内、ESP32 の 3.3V ロジックとも整合）。
`PROJECT_STATUS.md` の「DVDD = 2.5V 共通」という記述のほうが旧く、そちらが誤り。

基板は既に契約と一致しているので**やることは無い**（実測: FB5 pin1=VDD_ESP / pin2=DVDD、
DVDD 13 パッド・VDD_ESP 12 パッド、いずれも契約の員数と一致）。
契約に対する残差分は `gates/netlist_diff.json` の 16 件（ピン 8 ＋ 新設 4 部品のパッド 8）だけで、
それは S4 で全部消えている。**S5 は FB5 を触らないこと。**

### 取り込み時の既知欠陥（as-imported の期待どおりの FAIL・`13_fix_import.py` で修正）

機械可読な形は `gates/design_observations.json` の `known_import_defects`。
**いずれもデータの欠損ではない**（EasyEDA 側の 22 穴は 22 穴とも KiCad に入っている）。

| # | 症状 | 実測 | 修正方針 |
|---|---|---|---|
| 1 | **NPTH が 0 個** | 取付穴 6 個すべて幾何としては正しい位置にあるが、NPTH 属性のパッドは 1 つも無い | 下記 2・3 の修正で 6 個にする |
| 2 | M2 取付穴 ×4 が **PTH** | 無名フットプリント `Pad_e525`〜`Pad_e528`、drill = size = 2.3875mm、ネット無し | `SetAttribute(PAD_ATTRIB_NPTH)`・銅なし |
| 3 | USB-C ペグ ×2 が **Edge.Cuts の多角形** | J1 が持つ Edge.Cuts 形状（shape=POLY, 実効径 0.694mm）。位置は (56.861075, −33.877885) / (56.861075, −28.097861) mm ＝ブリーフの期待値と厳密一致 | NPTH パッドを生成し、Edge.Cuts の多角形は削除 |
| 4 | 設計ルールが空 | `.kicad_pro` は最小スタブ | JLC 4 層ルールを書き込む |

**ペグの正体（重要な訂正）**: 私は当初「ペグ穴は存在しない」と報告したが**誤り**だった。
実体は USB-C フットプリント（`109d95f4….efoo`）内の **`FILL` レコードで、layer 12 (Multi) 上の
CIRCLE パス r = 13.78 mil**（id `e36` / `e37`）。REGION でも PAD でもないので、
REGION と PAD の穴だけを見ていた初版の検出器が取りこぼしていた。
J1 の配置 (2290, −1220) mil・回転 90° を掛けると φ0.7000mm の 2 穴がブリーフの座標に
**小数 6 桁まで一致**する。`10_epro_inventory.py` は layer 12 の FILL/POLY/REGION の円を
すべて穴として拾うよう修正済み（EasyEDA 側の穴 20 → 22）。

なお ECO の L4 が言う「Slot Region e54/e55」はこの 2 つの FILL 円のことと**推測**されるが、
id が e36/e37 で一致しないため、S3 は L4 を実形状に対して取り直すこと。
この export に REGION プリミティブは 1 つも無い。

J1 はほかに CHASSIS_GND のメッキ済みスロット穴 4 個を持つ
（(56.3409/60.5410, −35.3130/−26.6630) mm、1.5×0.6 と 1.2×0.6 mm、パッド番号 13/14）。

### 取り込み時 DRC（参考値のみ）

`logs/drc_import.json`: violations **1025**（error 609 / warning 477）、unconnected **0**。
内訳上位は clearance 336 / silk_overlap 199 / lib_footprint_issues 131 / silk_over_copper 115 /
track_width 90 / courtyards_overlap 69。**KiCad 既定ルールに対する数字**なので、
設計ルールを入れるまで意味のある値ではない。

## S7 — ECO-5、レビュー、受け入れ判定

`ACCEPTANCE.md` は**凍結したまま一文字も変えていない**。S7 はその実装。

### S7a — ECO-5 と BOM 修正（`scripts/45_apply_eco5_and_bom.py`）

**ECO-5（銅箔の変更は 1 パッドだけ）**: `C_BIAS_INV` pad2 を `GND` → `BIAS_OUT_INT`。
これで容量が `R_BIAS_FB` の 1 MΩ と**並列**になり、BIAS 加算節点を GND に落とす
現状（位相余裕を削り、50 Hz での DRL 利得を失う）から TI SBAS499 の推奨形に戻る。

配線は素直ではなかった。2 つのパッドは **5.23 mm 離れており、その直線上に
`BIAS_INV` のパッドが 2 つ**（`C_BIAS_INV` 自身の pad1 と `R_BIAS_FB` pad1）ある。
表面を回り込むと 7 mm 超。**ところが `BIAS_OUT_INT` は B.Cu に
y = 87.7215 の 18.2 mm の幹線を持っていて、それが部品の真下を通っている。**
そこへ落とすほうが短い:

| | |
|---|---|
| via | (141.8852, 90.414) ← **旧 GND via はパッドの真下**にあった。0.55 mm 西へ動かしてランドから外した（0402 のパッド下 via はリフローではんだを吸う） |
| 表面スタブ | 0.5548 mm |
| B.Cu の降り | 2.6925 mm、既存幹線に着地 |
| 員数 | via 239 のまま（GND via を 1 個外して 1 個足した）、トラック 1250 → 1251 |
| ネット員数 | GND 86 → **85**、BIAS_OUT_INT 3 → **4**（契約と一致） |

部品は `C23967`（Samsung CL05B152KB5NNNC、1.5 nF 50V X7R 0402、JLC Extended）。
opusQ1 の選定で、S7 が独立に調べても同スペックを確認した。
**JLC Basic に 1.5 nF 0402 は 1 点も無い**（部品検索 API に `componentLibraryType=base`
を付けて走査、ヒット 0。同形式で `100nF 0402 + base` は `C1525` を返すのでフィルタは効いている）。
C0G が要るなら `C668348`（Murata GRM1555C1H152JA01D、同一 C0402）が代替になるが、
帰還 C の両端 DC 差は≈0 で X7R の DC バイアス減衰は効かず、
温度ドリフト ±15% も 1 MΩ∥1.5 nF の極 106 Hz を ±15% 動かすだけなので採らなかった。

**BOM 修正 8 件**（フットプリントは全て不変）: FB1〜FB5 → `C1017` /
`C_AVDD1_10n`・`C_VREFP_10n` → `C15195` / `C_VREFP_10u` の MPN を `CL31A106KBHNNNE` に訂正 /
`D_LED` → `C72044`（赤 Vf 1.95V）/ `C_EN_DLY` → `C52923`（1 µF）/
`C_BIAS_INV` → `C23967`。

**DNP 2 点**: `R_RST_UP`（ESP32 の IO12 起動ストラップ違反）と
`R_IO15_DN`（ROM ブートログが止まる）。**フットプリント・ネット・銅は基板に残し**、
`SetDNP` ＋ BOM/POS 除外だけを立てた。

そのために `lib/repair.py` を 2 つ直した:

- パリティ検査が `contract/contract_overrides.json` を適用するようになった
- **「BOM 除外 ＝ 機械部品」ではなくなった。** DNP 部品は実在する部品で
  ネットも持つので、パッド網の突合対象から外してはいけない
  （`mechanical = BOM 除外 かつ DNP でない`）

`19_make_parts_table.py` が `data/bom_fixes_2026-08-28.json` を**生成の最後に重ねる**ので、
CSV を再生成しても修正が消えない。品番だけを指定した修正（B2）では MPN を
C 番号から引き直す — そうしないと `C_EN_DLY` が「1 µF」と書かれた 100 nF の品番になる。

### S7b — アナログ配線は 1 件も動いていない（`scripts/46_analog_untouched.py`）

取り込み直後（git `22513e4`）と現在をアナログ 40 ネットについて 1 アイテムずつ突合。
**uuid ではなく幾何（ネット・層・座標・寸法）を鍵にする** — S5 が 2,625 個の uuid を
振り直しているので、uuid で突き合わせると全アイテムが「変更」に見える。

> **`IN1P`〜`IN8N`（差動 8 対）、`SRB1`、`*_ELEC` 11 本 ＝ コネクタから ADC までの
> 信号路の差分は 0 件。** 追加も削除も移動もリサイズも 1 つも無い。

その他のアナログ 12 ネットには 120 件の差分があり、**全件が記録から説明できた**。
説明は手で書き写すのではなく**記録から読む**ようにした:

- `logs/eco_apply.json` / `logs/eco5_bom_apply.json` は撤去・敷設したアイテムを座標付きで持っている
- `gates/S5_*.json` / `gates/S6.json` は解決した違反をネットと座標付きで持っている
- 修理前の DRC レポートは、その修理が動いてよい根拠そのもの

これが要るのは実際に 4 箇所あった。RESV1 のスタブ via は `U_ADS` から 7 mm 離れており
「部品の周囲◯ mm」では届かないし、AVDD の via が 0.89 mm 動いたのは
**取り込み時 DRC が最初に出した AVDD/AVSS の clearance** が理由だった。

#### 変化した銅箔の画像（`scripts/64_copper_xor.py`）

差分表の目視版。両方の基板を**同じ A4 枠・同じ倍率**でラスタ化し、画素ごとに
どちらに銅があるかを塗り分ける（灰＝両方／緑＝追加／赤＝削除）。
`reports/copper_xor_f_cu.png` / `copper_xor_b_cu.png`。

F.Cu で**基板左半分（12 ピンヘッダ・入力抵抗 16 個・CM コンデンサ 16 個・
そこから ADS1299 までの配線）が一様に灰色**であることが、「入力系の差分 0 件」の
目視版になっている。赤緑が固まっているのは ADS1299 北側・中央下（BIAS）・
右下（AMS1117 と USB-C）の 3 箇所だけ。
B.Cu 左上の赤緑の対は L2（CHASSIS_GND を H1 の外へ引き直した）そのもの。

**`pcb render` は 3D なので比較に使えない**（光源と遠近がある）。`export svg` は平面だが、
`--page-size-mode 2` は**内容に合わせて紙を切る**ので 2 枚の高さが 1421 と 1456 になり揃わない。
`--page-size-mode 0`（A4 固定）で出してから基板矩形だけをレンダリングしている。
なお nanosvg は "297mm" を 96 dpi で px に直すので、`scale` は mm ではなく
**その自然サイズに対する倍率**（1 mm = 3.7795 px）。ここを取り違えると
エラーではなく**真っ白な画像**が出る。

### S7c — レイアウト品質（`scripts/47_layout_quality.py` / `reports/layout_review.md`）

`docs/ads1299_layout_checklist.md`（opusQ3、一次資料ベース）の J1〜J11 を実測。
チェックリストが冒頭で釘を刺しているとおり
**TI はデカップリングの距離に数値基準を出していないので、距離は測定値として載せるだけで合否にしない。**
合否は TI が規則として書いている J1（バイパス C と IC の間にビアを置かない・同一層）で取る。

**実施した改善**: `C_VCAP3_H`（0.1 µF）が ADS1299 pin55 まで **5.95 mm・ビア 2 個**で、
1 µF の `C_VCAP3`（3.36 mm）より**遠かった** — 高周波バイパスとしては逆順。
**2.10 mm・ビア 0・全て F.Cu** に移した（`scripts/48_improve_vcap3.py`）。

先に 1 µF のほうを動かす案を試して**捨てた**: `C_VCAP3` を東に寄せると
`C_VCAP3_H` が 4.6 mm 先に取り残され、`plan_route` でも迷路ルータでも届かなかった。
**部品 1 個と、その部品だけに繋がる銅だけを触る**形にしたので、
失敗しても「経路が無い」で終わって基板は変わらない。

`C_VCAP1` / `C_VCAP3` / `C_VCAP4` はより近い合法位置が無い（`C_VCAP4` は 62 箇所探索）。

**測り方を 2 回間違えて直した。両方とも「あるように見えて無い問題」だった:**

1. GND ベタが無いサンプル点をそのまま数えると、**ビアのアンチパッド 187 点が
   「プレーン分割」に見えた**。全点がその配線自身のビアから 0.2 mm 以内で、
   リターン電流もそこで層を替える。原因別に分類したら**本物の断絶は 0**
2. J2（スター接続）をパッドの銅島にあるビアで判定すると「違反」と出たが、
   **これはレイアウトではなく回路図で決まる**。ピン 54 は `AVDD`、ピン 53 は `AVSS` に
   直結されていて**別ネットですらない**ので、銅箔をどう引いてもスターにはならない

### S7d — ACCEPTANCE A〜G（`scripts/50_final_check.py`）

32 項目すべて pass。**文書が挙げている数値をコードに書き写して測定値と並べてある**ので、
読む人は「文書を正しく読んだか」ではなく「コードと文書が一致するか」を確かめられる。
D と E は KiCad ではなく `lib/gerber_parse.py` が出力ファイルを読んで判定する。

## S8 — 製造データ

### 発注を止めていた欠陥: スルーホールのレジストが両面とも開いていなかった

**自前パーサで Gerber を読み直したから見つかった。**
B.Mask が 466 バイト — アパーチャ 0・フラッシュ 0・リージョン 0 の**空ファイル**だった。

原因は取り込み側。**PTH / NPTH パッド 22 個すべてが「銅箔層だけ」のレイヤ構成**
（F.Cu・B.Cu ＋ 内層 30 枚、F.Mask も B.Mask も無い）で入っていた。
SMD パッド 417 個は `F.Cu / F.Mask / F.Paste` で正常だったので、
表面のレジストには 403 開口があり**基板を見ているかぎり健全に見えた**。
DRC も何も言わない — 「開口を要求していないパッド」は違反ではない。

そのまま発注すると **`J2` の 12 ピンヘッダ全部と `J1` の USB-C シェル脚 4 本が
表裏ともレジストで覆われ、はんだ付けできない**。電極ケーブルが挿さらない基板になる。
2026-08-16 の EasyEDA パッケージは 22 個すべてを両面で開けているので、
**これは設計ではなく KiCad 取り込みが持ち込んだ退行**。

`scripts/43_fix_pth_mask.py` が 22 パッドに F.Mask / B.Mask を足す。銅箔は不変
（部品・トラック・via・パッド数が同一、パリティ 0、未接続 0、DRC error 0、新規違反署名 0）。
F.Mask 403 → 425 開口、B.Mask 0 → 22 開口、J2 の 12 ピンが両面で開いていることを
プロット済みデータで再確認し、`fab/preview_bottom.png` でも金色に見える。

**教訓**: KiCad に自分の出力を読み直させても、**自分と矛盾していないこと**しか分からない。

### 外形の Gerber が `Multi-Layer.gm1` という名前で出ていた

取り込みが EasyEDA のレイヤ名を KiCad の表示名として引き継いでいたため、
出力ファイル名が `Therapia_EEG-HRV-Multi-Layer.gm1`（外形）、
`...-Top Solder Mask Layer.gts` のようになっていた。拡張子と X2 属性
（`TF.FileFunction,Profile`）は正しいので機械は間違えないが、
**EasyEDA の "Multi-Layer" は「全層」の意味**であり、それがルータの切断線を決める
ファイルの名前になっているのは人が読み違える。名前に空白が入るのも、他社の受付を通すうえで不要な引っかかりになる。
`scripts/49_normalize_layer_names.py` が KiCad 正規名に戻した。
表示名だけの変更である証拠: 基板本体はレイヤを正規名でしか参照していない
（`(layer "F.Cu")` が 1079 箇所、`(layer "Top Layer")` が 0 箇所）。

### 出力（`scripts/60_export_fab.sh` / `61_make_bom_cpl.py`）

設定は **JLC が実際に受理した `ganglion_clone/jlcpcb_order` に合わせた**:
Protel 拡張子・X2・4.6 mm・Excellon は PTH/NPTH 分割でメートル法 decimal・絶対座標。
どれも kicad-cli 10 の既定なので、コマンドラインに並んでいるのは既定と違う分だけ。

| 成果物 | 中身 |
|---|---|
| `fab/Therapia_EEG-HRV_Rev.A.zip` | Gerber 11 ＋ `.gbrjob` ＋ ドリル 2 ＝ **14 ファイル** |
| `fab/BOM_JLCPCB.csv` | **31 行 / 133 点**。全行に LCSC あり |
| `fab/CPL_JLCPCB.csv` | **133 行**、全て Top |
| `fab/preview_top.png` / `preview_bottom.png` | 3D レンダ |
| `fab/assembly_top.pdf` | 部品番号入り実装図。**DNP 2 点に × が入る** |
| `fab/README_発注手順.md` | JLC 設定・投入前の確認 4 点・在庫監視・Extended 13 品番・発注しない条件 |

BOM の Footprint 列は **CSV のパッケージ表記ではなく基板のフットプリント名**から取る。
CSV の表記は 3 箇所で誤っている（`D_LED` が 0603 のランドなのに "0805"、
`C2840012` と `C19619` は `csv_label_fixes` に記載）。**作るのは基板のほう。**

### 独立パーサ（`scripts/lib/gerber_parse.py` / `62_check_fab.py`）

標準ライブラリだけの RS-274X ＋ Excellon リーダ。
C/R/O/P アパーチャと KiCad の `RoundRect` マクロ、G36/G37 リージョン、
G75 円弧、LPD/LPC 極性を扱う。**未知のマクロは外接円に落とす** —
穴クリアランス検査で銅を過大評価する側なので、誤警報は出しても見逃しは出さない。

実測:

| 検査 | 結果 |
|---|---|
| 外形 | **61.8236 × 45.0088 mm**（2026-08-16 版と一致） |
| NPTH 6 穴 | 全て ACCEPTANCE D の座標から **0.3 µm 以内**、径も一致 |
| 穴 + 0.2 mm 内の銅 | **4 銅箔層すべてでゼロ** |
| ベタ充填 | In1 **95.4%** / In2 **93.6%**（内層が実際に埋まっている） |
| 銅箔層の極性 | 加算のみ（LPC 無し）＝ 上の判定が減算を見落としていない |

**極性の扱いは途中で直した。** `--subtract-soldermask` が吐く `%LPC%` の
クリアリージョンを加算として数えていたため、実際は空の B.SilkS が
「22 個の図形を持つ」ように見えていた。

### 製造データを 3 系統で照合した（S8 の追加分）

同じ事実を KiCad の**別々の書き出し経路**から出させて突き合わせた。
1 つのファイルが自分と矛盾していないことより、3 つが一致することのほうが証拠になる。

| 経路 | 何を言っているか | 実測 |
|---|---|---|
| Gerber ＋ X2 属性 | 各フラッシュのネット | Top 面 SMD **417/417** が d356 と一致 |
| `fab/board.d356`（IPC-D-356） | 各パッド・ビア・穴のネットを**データとして** | 678 features（via 239 / SMD 417 / PTH 16 / NPTH 6）、未解釈行 0 |
| `fab/odb/`（ODB++） | ネット名一覧とネットリスト点 | ネット **79**、点 **678 = パッド 439 ＋ ビア 239** |
| `.gbrjob`（JSON） | 層数・板厚・スタックアップ・設計ルール | 4 層 / 1.6 mm / 銅 4 層 / TrackToTrack 0.0889 |

ネット数は **契約 79 = Gerber X2 = IPC-D-356 = ODB++**。過不足なし。

`.gbrjob` の `Size` は 61.9252 × 45.1104 で、これは外形 61.8236 × 45.0088 に
Edge.Cuts のペン幅 0.1016 を足した値。**`centreline_bbox` が正しいものを測っている
という独立の裏付け**になっている。

#### X2 属性の罠（実測で確認）

KiCad は `%TO.N,<net>*%` を**ネットが変わったときだけ**出し、以降は `%TD*%` で
消えるか上書きされるまで効き続ける。**F.Cu だけで属性設定 934 回・削除 178 回に対し
フラッシュは 672 個**なので、大半のフラッシュは離れた行の属性を継承している。
「D03 の直前行に TO.N がある」という前提で読むと**黙って間違ったネットを割り当てる**。
`lib/gerber_parse.py` は `{TO.N, TO.P, TO.C}` の状態機械で持ち、`%TD*%` で全消去する。

#### IPC-D-356 で出来ること・出来ないこと（推測せず実測した）

**出来る**: ネット集合（欄 14 文字、本基板の最長ネット名 `STATUS_LED_DRV` が
ちょうど 14 文字なので切れていない）、NPTH 6 穴の識別と非メッキ判定、feature 員数。

**出来ない**: 部品番号の欄が **6 文字**しかなく、この基板の designator は最長 12 文字。
6 文字に切ると **135 個が 97 種類に潰れる**（`C_AVDD` 12 個・`C_3V3_` 7 個・
`C_AVSS` 6 個・`C_VCAP` 6 個・`C_DVDD` 5 個…）。
→ **ACCEPTANCE B（部品→パッド→ネット）には使えない。** そちらは pcbnew が正。

座標分解能も 0.0001 inch = **2.54 µm** なので、ACCEPTANCE D の「±2 µm」判定は
Excellon（メートル法・µm 精度）に残し、IPC-D-356 は自分の分解能での照合に使っている。

### DRC はプロジェクトディレクトリでしか回してはいけない（実測で確認）

`lib/repair.run_drc()` は、基板が `.kicad_pro` と `.kicad_dru` の隣に無ければ
**実行を拒否する**ようにした。同じ基板を単体で別ディレクトリにコピーして
DRC を掛けると:

```
プロジェクト同梱:  violations  470   error   0
基板だけコピー:    violations 1248   error 727   ← 何の警告も出ない
```

KiCad 既定ルールに黙って落ちるだけで、エラーにはならない。
なお `--exit-code-violations` の戻り値は **5**（`-ne 0` で判定すること）。

### 標準ライブラリだけで動くことを S0 が検定するようになった

KiCad 同梱 python では PIL・numpy・matplotlib が**import できてしまう**が、
実体は `~/Library/Python/3.9`（このマシンのユーザ site）で、KiCad の一部ではない。
`PYTHONNOUSERSITE=1` を掛けると全部消え、それでも `lib/` の 10 モジュールは
すべて import できる — これを S0 の 12 番目のチェックにした。

### 8 月版との照合 — 一番強い証拠

`fab/CPL_JLCPCB.csv` を 2026-08-16 の CPL と突合（座標系は (120, 80) 平行移動 ＋ Y 反転）:

- **129 部品中 122 が位置・回転とも完全一致**
- 動いた 7 点は全て記録済みの判断: `AMS1117` +3.25/−1.25（L1、H4 から退避）、
  `C_VCAP1` 2.50 mm＋90°・`C_VREFP_10u` 0.57 mm＋90°（ECO-3 の 1206 化）、
  `C_AVSS_B` +0.15 / `C_VREFP_10n` +0.05 / `C_3V3_H` 0.05 / `C_RST_DLY` 0.10（S5 の微動）
- 新規 4 点 = ECO-1/ECO-3 の `C_VCAP1_H` `C_VCAP2` `C_VCAP3` `C_VCAP3_H`
- 「消えた」2 点 = DNP の `R_RST_UP` `R_IO15_DN`（正しく除外されている）

> **旧 STATUS の訂正**: S5 は `C_RST_DLY` の移動を「−0.05 mm」と記録していたが、
> 8 月版に対する実測は **−0.10 mm**。S5_L5 のログは 1 反復ぶんの値で、
> S6 のループがもう一度動かしていた。基板が正で、DRC も通っている。

## S9 — カート投入（2026-08-28 18:46 → 21:12 に修正版で再投入、決済なし）

結果は「現在地」と `gates/S9.json`。ここには**手順どおりに行かなかった点**だけ残す。

0. **JLC の Component Placements は最後の物理チェックとして本気で見ること。** 18:46 版は BOM・極性・
   DRC 全部通っていたのに、3D モデルを見たユーザーの一言「MCU と ADS が重なって見える」が正しかった。
   再投入の手順は初回と同じ（Gerber → パネル化 → ENIG → PCBA 設定 → BOM/CPL → 部品照合 → 配置 → 見積 → 保存）で
   約 15 分。古い品目はカートの行のゴミ箱 → ポップオーバーの Delete（in-page、ネイティブ dialog ではない）

1. **Economic は使えなかった。** ESP32-WROOM-32E が「Standard Only」。Standard は単板 70×70 mm
   以上が条件なので、PCB タブの Delivery Format を **Panel by JLCPCB（1×1、Edge Rails: four sides
   12.5 mm）** にして 86.82×70.01 mm にした。PCBA 数量の単位はパネル（最小 2）
2. **在庫は BOM 画面で初めて分かる。** partdetail ページや LCSC の在庫は当てにならない。
   `C72044` と `C72038`（Everlight 19-217 系）は JLC 在庫 0（廃番）、`C369159` も 0。
   BOM 行の虫眼鏡 → C 番号検索 → Select で差し替えると自動保存される
3. 予定していた F1 代替 `C883122`（6 V）は一度選んだあと、旧品と定格が同じ 13.2 V の
   `C43379` に替えた（同じ F1206 パッド）
4. JLC の自動照合は `U_USB` を C7464026 に当てた（同じ WCH CH340C の別リスティング）。
   repo BOM と揃えるため `C84681` に戻した。**カートの 31 行を repo BOM と C 番号で突合すること**
5. Confirm Parts Placement のビューは**右表の行をクリックすると部品にズーム**し、
   **紫の点が JLC ライブラリの pin 1**、LED は「−/+」で出る。右表はホイールで動かず
   スクロールバーをドラッグする。突合の相手は `pcbnew` で出した各パッドの dx/dy/net
   （y は下向き正）。SOT-23 系で恐れていた 270° 食い違いは出なかった
   （EasyEDA 由来のフットプリントをそのまま取り込んだので回転基準が JLC と同じ）
6. Product Description（HS コード）は必須。Research/Education/DIY → Development Board
   (HS 847330) にした。決済前に変更可
7. ブラウザ操作: 入力欄で cmd+A はページ全選択になる → triple_click で欄内を選択してから type

**Confirm Parts Placement の応答が 72 h 以内に必要**（決済後に JLC がメールで指摘を出す）。
`D_LED` の向きは「− が GND 側（左）」、`U_ADS` は pin 1 左上、で答える。

### 未解決・人の判断が要るもの

| # | 内容 | いま何をしているか |
|---|---|---|
| A-6 | **AVDD1(54) / AVSS1(53) がスター接続でない。** 回路図が `AVDD` / `AVSS` に直結しており別ネットですらないので **PCB 側では直せない** | Rev.A 受容。火入れで AVDD のリップルを実測して Rev.B の判断材料にする |
| J1 | `C_VCAP1`(100 µF) が pin28 から 9.89 mm・銅箔 12.16 mm・ビア 2 個。`C_VCAP4` も 5.24 mm / ビア 2 個 | より近い合法位置が無いことを探索で確認済み。TI は距離の数値基準を示していない |
| J4 | `C_VCAP1` が **X5R**。TI DS §11 は振動環境の VCAP1 に C0G/NP0 かタンタルを推奨 | Rev.A 受容。装着型なので Rev.B で要検討 |
| M1 | **AMS1117 の本体が取付穴 H4 の真上** | 筐体側で対応（上面にネジ頭を置かない）。`10_enclosure_design.md` に反映すること |
| — | In2 の `VDD_ESP` ベタ 3 枚のうち 1 枚が充填後ほぼ面積ゼロ（< 0.005 mm²） | 残り 2 枚が配電している。実害なし |
| — | `U_MCU` のアンテナが基板内側（右端から 6.34 mm 内側） | Rev.A 受容 |

### 必ず知っておくべきこと

1. **重複 KIID は直したが、それが何を意味するかは覚えておくこと。**
   取り込み直後の基板は 231 個の uuid を複数アイテムで共有していた（38 部品が同じ 1 個）。
   KiCad の DRC は違反アイテムを **KIID で保存して後から引き直す**ので、
   重複があるとレポートが**別の部品を名指しする**。`26_fix_uuids.py` が採番し直した。
   **`11_import_epro.py` からやり直す場合は、S5_uuids を必ず先に通すこと。**
   `scripts/lib/route.uid()` も KIID 単独では一意でないので、パッドと部品は
   reference とフットプリント相対座標を足した鍵を返すようにしてある
2. **DRC レポートの `pos` は違反の位置ではない。** アイテム自身のアンカー
   （トラックなら始点）なので、11 mm のトラックだと違反箇所と数 mm ずれる。
   位置が要る処理は `scripts/lib/repair.py` の
   `clearance_pairs` / `hole_pairs` / `copper_near_hole` で**自分で幾何から出す**
3. **DRC 件数で判定しないこと。** 同一入力で 525〜531 件と揺れる。
   `scripts/lib/drc.py` の署名比較（種別＋ネット集合）を使う
4. **`pcbnew` は 1 プロセスで 2 回 `LoadBoard` できない。** DRC を回すスクリプトと
   基板を編集するスクリプトは分けること（S6 がその形）
5. **DRC はコマンドサンドボックス内では落ちる。** サンドボックス外で実行する
6. **FB5 は触らないこと。** 決着済み。契約どおりで基板も一致している
7. **KiCad に自分の出力を読み直させても、自分と矛盾していないことしか分からない。**
   S8 の PTH レジスト欠落は、`kicad-cli` が書いた Gerber を
   `lib/gerber_parse.py` で読んだから見つかった。基板を見ても DRC を回しても
   出てこない種類の欠陥がある（「開口を要求していないパッド」は違反ではない）
8. **「BOM 除外」は「機械部品」ではない。** DNP 部品は実在してネットも持つので、
   契約との突合対象から外してはいけない。`repair.pad_net_map` の判定は
   `BOM 除外 かつ DNP でない` になっている
9. **ベタの欠落を数えるときはアンチパッドを除くこと。** 素直に数えると
   ビア周りの穴 187 点が「プレーン分割」に見える。原因（自ネットのビア /
   他ネットのビア / 説明のつかない空白）で分類する
10. **Gerber の `%LPC%`（クリア極性）を加算として数えないこと。**
    `--subtract-soldermask` はレジスト開口を**シルクから引く**ために
    クリアリージョンを出すので、実際は空の B.SilkS が「22 図形」に見える
11. **`export pdf --mode-single` の `--output` はディレクトリではなくファイル。**
    ディレクトリを渡すと "Failed to create file" とだけ言って終わる
12. **DRC は必ずプロジェクトディレクトリで回す。** 基板だけコピーすると
    KiCad 既定ルールに黙って落ちて 1248 件（error 727）になる。
    `run_drc()` が拒否するようにしたが、別経路で回すときは自分で気をつけること
13. **Gerber X2 の `%TO.N%` はスティッキー。** ネットが変わったときだけ出力され、
    `%TD*%` まで効き続ける。直前行を見る実装は黙って誤ネットを割り当てる
14. **IPC-D-356 の designator 欄は 6 文字。** この基板では 135 個が 97 種類に潰れるので
    部品単位の突合には使えない。ネット欄は 14 文字で足りている

### 使えるもの

| ファイル | 何ができるか |
|---|---|
| `scripts/42_board_facts.py` | 上表を基板から再測定して JSON で出す。ゲートはこれを引用する |
| `scripts/29_drc_report.py` | 保存済み DRC レポートを種別ごとに整形。`--type` `--json` |
| `scripts/28_board_inspect.py` | KIID / reference / ネット / 座標でアイテムを引く |
| `scripts/27_net_islands.py` | ネットが電気的に分断されていないかを保存前に見る |
| `scripts/40_drc_loop.py` | 何か直したあとに回せば、DRC が clean になるまで自動で追い込む |
| `scripts/39_fix_unconnected.py` | DRC が unconnected を出したとき、その 2 点を繋ぎ直す |
| `scripts/62_check_fab.py` | 製造データを**自前パーサ**で読み直す。KiCad も kicad-cli も使わない |
| `scripts/50_final_check.py` | ACCEPTANCE A〜G を 32 項目で判定（`gates/S7.json`） |
| `scripts/47_layout_quality.py` | ADS1299 チェックリスト J1〜J11 を基板から実測 |
| `scripts/46_analog_untouched.py` | 任意の過去コミットとアナログ配線を突合。`--baseline <sha>` |

## 途中で直した問題

| 問題 | 対処 |
|---|---|
| EasyEDA Pro 3.2 が書き出す `.epro2` を KiCad が**無言で空基板として**読む | 形式を判定（S1）し、旧 `.epro` へ変換する S1B を追加。今回は正規の旧 `.epro` が用意されたのでそちらを採用 |
| 同一番号パッドの 2 枚目以降にネットが付かない（GND 90→82 / CHASSIS_GND 5→3） | 取り込み後に EasyEDA の表を全パッドへ再適用。10 パッド補修、DRC の unconnected 2→0 |
| `kicad-cli pcb drc` がサンドボックス内で Swift エラー落ち | サンドボックス外で実行。README に明記、スクリプトも検知してヒントを出す |
| 外形が 61.925 × 45.111 と出る | `GetBoardEdgesBoundingBox()` が線幅 4mil を含むため。Edge.Cuts の中心線から算出するよう変更 |
| 層別比較が全件不一致になる | 取り込み後の層名が EasyEDA 表記（"Top Layer"）のまま。`GetStandardLayerName()` で正規名に揃えて比較 |
| `wx.App()` が headless で `SystemExit` を投げ子プロセスごと落ちる | `pcbnew` は wx 無しで動くので生成しない |
| **`id()` が pcbnew では使えない** | SWIG は基板から取り出すたびに別のプロキシを返すので、同じパッドを 2 回取ると `id()` が違う。無視リストが全部壊れ、ECO スクリプトが「自分自身と衝突する」と言い続けた。`lib/route.uid()`（KIID 文字列）に統一 |
| **`board.Remove()` が SWIG の型情報を壊す** | board 直下の要素を消すと以後 `GetFootprints()` が生の `SwigPyObject` を返す。`RemoveNative()` は壊さない。footprint 内の要素は先に集めてから消せば `Remove()` で可 |
| **`pcbnew.FOOTPRINT(src)` は KIID ごと複製する** | 複製した部品のパッドが元と同じ uuid を持つ（実測）。`m_Uuid` は書き込み不可、`FixUuids()` も効かない。新設部品はゼロから組み立てる（`make_chip_footprint`） |
| **`LoadBoard` / `SaveBoard` の後は基板を走査できない** | 同一プロセスで 2 回目の `LoadBoard`、および `SaveBoard` の後は proxy が生のオブジェクトになる。計測は保存前に済ませる |
| **DRC が非決定的** | 同じ基板で 525／528／531 件と揺れる。原因は同一箇所を代表する要素の選ばれ方。`lib/drc.py` の署名比較で吸収 |
| **KIID が一意でない（S5 の最大の発見）** | EasyEDA インポータがライブラリ部品の全インスタンスに同じ KIID を振る。231 個の uuid が重複、うち 1 個は 38 部品で共有。KiCad は uuid の一意性を前提にしており、`BOARD::GetItem(KIID)` は最初に見つけたものを返す。**DRC は違反アイテムを KIID で保存して後から引き直す**ので、レポートが別の部品を名指しする ── 9.3 mm 離れたパッド同士の `solder_mask_bridge`、8.9 mm 離れたパッド同士の 0.0420 mm `clearance`、VDD_ESP のはずが USB_5V のパッドを掴んだ結線修復（24.7 mm・106 本のトラックを敷いた）。**種別と件数は常に正しく、間違っていたのはアイテムの同定だけ**。`26_fix_uuids.py` が 2,625 個を採番し直した（基板の幾何・ネットは不変を検証済み） |
| `lib/route.uid()` が KIID 単独だった | 上記の重複により、`ignore` リストが無関係な部品まで無視し、`CopperIndex` のクエリ内重複排除が本物の障害物を捨て、接続性チェックが 38 パッドを 1 ノードに融合していた。パッドは reference ＋フットプリント相対座標、部品は reference を鍵に足した。相対座標なのは、部品を動かしても鍵が変わらないようにするため |
| DRC レポートの `pos` は違反の位置ではない | アイテム自身のアンカー（トラックなら始点）。11 mm のトラックだと違反箇所と数 mm ずれる。位置が要る処理は `lib/repair.py` の `clearance_pairs` / `copper_near_hole` で幾何から出す |
| ゾーンの塗り潰しを穴なしで再構成すると全部繋がって見える | `net_components` の初版が `SHAPE_POLY_SET::Outline(i)` だけを足していた。ベタは「1 本の外形＋異ネットのパッドごとに開けた穴」なので、穴を落とすと板全体が 1 枚の銅になる。`HoleCount`/`Hole` も足す |
| 同一ネットのゾーンが複数あると分断に見える | VDD_ESP は 3 枚のベタに分かれている。重なっているベタ同士は 1 つの導体なので、フィル島同士も併合する |
| 結線修復が板を横断する | 上限を付けないと、切れた VDD_ESP に対して 24.7 mm・106 セグメントの経路を「合法だから」と敷く。`MAX_HEAL_MM` と、直線距離の 3 倍という上限を入れた |
| 迷路ルータの結果が階段状 | 8 方向グリッドは等コスト経路が大量にあり、A* は最初に到達したものを返す。H1 の迂回が 25 セグメントになった。経路を string-pull（見通しの利く限り直線に置き換える）してから採用する |
| 部品微動が「成功」と言って何も直さない | 合法性検査が自部品のパッドと自部品に付いた配線を無視するので、その 2 者の近接（C_RST_DLY のケース）が見えない。移動後に**実際のペアの隙間**を測って検証する |
| 端点にある違反は迂回では直らない | トラックの端点そのものが違反位置だと、同じ両端の間をどう引き直しても直らない。`retreat_track_end` で角ごと（そこに集まる配線ごと）動かす |

## 成果物

```
ACCEPTANCE.md                      発注可の定義（凍結）。最終ゲートの仕様
data/parts_lcsc.csv                designator -> Value / MPN / LCSC（135 行、ECO-2/3 込み）
board/Therapia_EEG-HRV.kicad_pcb   ECO 適用＋L1〜L5 修理済み。DRC error 0 / unconnected 0
board/Therapia_EEG-HRV.kicad_pro   JLC 4 層ルール／ネットクラス／severity（14_make_rules.py が生成）
board/Therapia_EEG-HRV.kicad_dru   NPTH hole clearance と 5mil 推奨の custom rule（同上）

--- S7/S8 で足したもの ---
scripts/43_fix_pth_mask.py         PTH/NPTH 22 パッドのレジスト開口を復旧（**発注を止めていた欠陥**）
scripts/45_apply_eco5_and_bom.py   ECO-5 の銅箔変更＋BOM 修正＋DNP。冪等
scripts/46_analog_untouched.py     アナログ 40 ネットを取り込み直後と突合。幾何を鍵に
scripts/47_layout_quality.py       ADS1299 チェックリスト J1〜J11 の実測
scripts/48_improve_vcap3.py        バイパス C を「より近く・ビア無し」の位置へ。条件を満たさなければ保存しない
scripts/49_normalize_layer_names.py  レイヤ表示名を KiCad 正規名へ（Gerber のファイル名が直る）
scripts/50_final_check.py          ACCEPTANCE A〜G（32 項目）
scripts/60_export_fab.sh           Gerber / ドリル / プレビュー / 実装図 / zip
scripts/61_make_bom_cpl.py         JLC 書式の BOM・CPL ＋ 8 月版 CPL との照合
scripts/62_check_fab.py            製造データの独立検査
scripts/63_gate_s8.py              製造パッケージのゲート
scripts/lib/gerber_parse.py        RS-274X / Excellon リーダ（標準ライブラリのみ）。X2 属性の状態機械つき
scripts/lib/ipcd356.py             IPC-D-356 リーダ（80 桁固定長。座標は aux 原点 (120,80) mm・Y 反転）
scripts/64_copper_xor.py           取り込み時と現在の F.Cu/B.Cu を画素単位で比較した画像（標準ライブラリで PNG を書く）
reports/copper_xor_f_cu.png reports/copper_xor_b_cu.png  同上の出力
fab/README_発注手順.md              JLC 発注の手順と、投入前に人が見る 4 点
reports/analog_diff.md             アナログ配線の差分と、その全件の由来
reports/layout_review.md           レイアウト品質の実測と改善の記録
gates/S7a.json S7b.json S7c.json S7.json S8.json
logs/eco5_bom_apply.json           ECO-5 の全操作
logs/pth_mask_fix.json             レジスト開口を戻した 22 パッド
logs/vcap3_improve.json            C_VCAP3_H の移設
logs/layout_quality.json           J1〜J11 の実測値
logs/bom_cpl.json                  BOM/CPL の突合と 8 月版との照合
logs/drc_s7a.json drc_s7c.json drc_s8_maskfix.json drc_final.json

--- S5/S6 で足したもの ---
scripts/26_fix_uuids.py            重複 KIID の採番し直し。**S5 の最初に必ず通す**
scripts/27_net_islands.py          ネットの電気的分断を保存前に見る
scripts/28_board_inspect.py        KIID/reference/ネット/座標でアイテムを引く
scripts/29_drc_report.py           保存済み DRC を種別ごとに整形
scripts/30_repair_L1.py 〜 34_repair_L5.py   L1〜L5 の修理本体
scripts/35_mask_bridges.py         レジスト開口の合体をパッド個別マージンで解消
scripts/39_fix_unconnected.py      DRC の unconnected を読んで 2 点を繋ぎ直す（別プロセス用）
scripts/40_drc_loop.py             DRC 自動ループのドライバ（素の python3）
scripts/41_drc_fix_pass.py         1 反復ぶんの修正（KPY）
scripts/42_board_facts.py          ゲートが assert する事実を基板から再測定
scripts/lib/maze.py                2 層 A* ルータ（via 遷移つき・DRC と同じ判定・経路を直線化）
scripts/lib/repair.py              ルール値・穴距離・接続性・修理プリミティブ・ゲート雛形
scripts/lib/viol.py                DRC レポートを作業リストに変換
gates/S5_uuids.json S5_L1..L5.json S5_mask.json S6.json
logs/drc_S5_before.json            S5 開始時（＝S4 直後）の DRC
logs/drc_after_L1.json 〜 drc_s5_l5.json   各修理後の DRC
logs/drc_after_uuidfix.json        KIID 修正直後（初めてアイテム同定が正しくなった DRC）
logs/drc_loop_NN.json              S6 の各反復
logs/drc_s6_final.json             最終 DRC（error 0 / unconnected 0）

--- S3/S4 まで ---
scripts/lib/route.py               衝突判定・スタブ除去・2 層ルータ・配置探索
scripts/lib/drc.py                 DRC の揺れを吸収する署名比較
gates/S3.json S4.json S4a.json
logs/drc_baseline_rules.json       ECO 前・JLC ルールでの DRC（S4 の比較基準）
logs/drc_after_eco.json            ECO 後の DRC
logs/eco_apply.json                ECO の全操作ログ
logs/rules_applied.json            採用したルール値と EasyEDA 値との突合
gates/S0.json S1.json S1B.json S2.json S2B.json
gates/inventory_easyeda.json       EasyEDA 側の員数表（基準）
gates/inventory_kicad.json         KiCad 側の同じ測定
gates/design_observations.json     ECO 状態・FB5・取り込み既知欠陥・DRC 内訳
gates/schematic_solver_accuracy.json  自前の回路図解きを契約 TSV と全数照合した結果
gates/netlist_diff.json            回路図 ↔ PCB の差分＝ECO-1 の残作業（S3 の作業指示）
contract/netlist_contract.json     回路図ネットリスト（ピン名付き・正）
contract/netlist_from_epro_pcb.json        designator→パッド→ネット（PCB の実態）
contract/netlist_from_epro_schematic.json  同（自前の幾何解き・参考）
contract/netlist_from_kicad_pcb.json       取り込み後の KiCad 側
contract/easyeda_rules.json        EasyEDA 設計ルール（未移植・S3 が書き写す）
logs/drc_import.json               取り込み時 DRC
logs/pad_net_repair.json           パッド網補修の記録
logs/import_attempts.json          パッチ段階ごとの試行結果
```

### ネットリストが 2 系統ある。正はどちらか

| ファイル | 由来 | 位置づけ |
|---|---|---|
| `contract/netlist_contract.json` | `contract/netlist_easyeda_api_2026-08-28.tsv`（EasyEDA の `sch_ManufactureData.getNetlistFile()` 出力、135 部品 / 423 ピン、**ピン名付き**） | **正**。回路図の意図。S3 の契約 |
| `contract/netlist_from_epro_pcb.json` | `.epcb` の `PAD_NET` ＋ `.efoo` のパッド | **正**。現在の基板の実態 |
| `contract/netlist_from_epro_schematic.json` | `.esch` の幾何を自前で解いたもの | **参考のみ**。相互確認用 |

TSV は本作業中に外部から `contract/` に置かれたもの（13:00）で、こちらで生成したものではない。
中身は ECO-1 適用後の回路図と完全に整合している（TPS72325 EN=`V_NLDO_IN`、RESV1=`GND`、
GPIO1–4=`GND`、C_VCAP2/3/3_H/1_H 在り）。

自前の幾何解きを契約 TSV と全数照合した結果（`gates/schematic_solver_accuracy.json`）:

- **NC ピン 34 本を 34/34 正しく特定**（過不足ゼロ）
- 解決したピン 375 本のうち **366 本は契約と一致、9 本が不一致**
  — `R_IN1N`〜`R_IN8N` と `R_SRB_SER` の pin1 で `SRB2` と誤答（正は `SRB1`）。
  `SRB2` はネットとして実在しない（PCB にも契約にも EasyEDA の NET 宣言にも無い）。
  SRB1/SRB2 を意図的に束ねてある箇所で、ワイヤ側に残った旧ラベルを拾ったもの
- **7 部品を丸ごと取りこぼし**: `R_EN_UP` `R_IO0_UP` `R_IO15_DN` `R_IO2_DN` `R_LED`
  `R_Q_EN_B` `R_Q_IO0_B`（ESP32 のブート/リセット周り）

つまり実用精度 97.6%・部品欠けあり。**相互確認以外に使わないこと。**
ピン名が要る作業では必ず TSV 由来の `netlist_contract.json` を使う（PCB にはパッド番号しか無い）。

## 再実行の仕方

```sh
./run.sh --status     # 現状確認
./run.sh              # 未完ステップから再開（全 pass 済みなら何もしない）
./run.sh --force      # 全部やり直し
python3 scripts/99_selftest.py   # 合成データでパーサを検証（24 チェック・KiCad 不要）
```

DRC を含むステップだけはサンドボックス外で実行すること。

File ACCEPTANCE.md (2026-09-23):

# ACCEPTANCE — 「発注可」の定義

凍結: 2026-08-28 / 担当 S3。**以後この文書は変更しない。**
最終ゲート `scripts/50_final_check.py` はこの文書の仕様そのものとして実装される。

この基板は Brain Canvas Rev.A（Therapia EEG/HRV、4層・61.8236 × 45.0088 mm）。
「発注可」＝ 下の A〜G が**全て pass** した状態を指す。1 つでも落ちたら発注しない。

---

## A. DRC

| 条件 | 値 |
|---|---|
| error 級の違反 | **0 件** |
| 未接続（unconnected items） | **0 件** |
| ゾーン | 再フィル済みで保存されていること |

判定は `kicad-cli pcb drc --format json --severity-error --severity-warning`
（**`--refill-zones --save-board` を掛けた後の基板に対して**）。
warning は残ってよいが、下の許容リストに載っている種別だけ。

### warning へ落とす種別（許容リスト・これ以外は error のまま）

| 種別 | 落とす理由 |
|---|---|
| `courtyards_overlap` | EasyEDA 由来のコートヤードは実寸より大きく、既存配置で 69 件出る。実装可否は CPL 実績（2026-08-16 版と同一配置）で担保する |
| `silk_overlap` / `silk_over_copper` / `silk_edge_clearance` | シルクは EasyEDA が自動生成したもの。製造には影響しない |
| `starved_thermal` | ゾーンのサーマルスポーク本数。GND ベタは面で繋がっており実害なし |
| `track_dangling` / `via_dangling` | ベタ止めのスティッチ via を含む。断線には当たらない |
| `isolated_copper` / `copper_sliver` | 再フィル後のベタ島。面積が小さく実害なし |
| `holes_co_located` | 同位置の穴。J1 のスロット穴に出る |
| `footprint_type_mismatch` | 取り込んだフットプリントは `attr` 未設定（smd/through_hole フラグ無し）。実体は正しい |

### ignore にする種別

| 種別 | 理由 |
|---|---|
| `lib_footprint_issues` / `lib_footprint_mismatch` | フットプリントライブラリを紐付けていないため 131 件出る。基板内の実データは EasyEDA と一致済み（S2 17/17） |
| `missing_courtyard` / `pth_inside_courtyard` / `npth_inside_courtyard` | 取付穴とコートヤードの関係は L1 で個別に見る |

**error のまま維持しなければならない種別**（緩めた時点でこの ACCEPTANCE は無効）:
`clearance` `hole_clearance` `hole_to_hole` `hole_near_hole` `copper_edge_clearance`
`shorting_items` `tracks_crossing` `unconnected_items` `track_width` `annular_width`
`drill_out_of_range` `invalid_outline` `items_not_allowed` `padstack`
`solder_mask_bridge` `zone_has_empty_net` `zones_intersect` `malformed_courtyard`
`through_hole_pad_without_hole` `connection_width` `creepage`

## B. ネットリスト＝契約

PCB の**全パッドの designator→pad→net 表**が `contract/netlist_contract.json` と一致すること。

- 部品 **135**（契約に載る designator 集合と完全一致）
- 全ピン一致。契約が NC（net 空）としているピンは PCB 側も無ネット
- 差分 **0**。1 件でもあれば fail
- 取付穴 `H1`〜`H4` は契約外の機械部品として除外される（NPTH・銅なし・BOM/POS 除外が条件）

## C. 設計ルール（JLCPCB 4層）

`board/Therapia_EEG-HRV.kicad_pro` と `board/Therapia_EEG-HRV.kicad_dru` が
`scripts/14_make_rules.py` の生成物と一致すること（冪等なので再生成して差分 0）。

| 項目 | 値 [mm] | 級 |
|---|---|---|
| clearance（最小・ネットクラス／`min_clearance`） | **0.0889**（3.5 mil） | error |
| track 幅（`min_track_width`） | **0.0889** | error |
| hole-to-hole（`min_hole_to_hole`） | **0.2** | error |
| hole clearance 穴→他ネット銅（`min_hole_clearance`） | **0.2** | error |
| 基板端クリアランス（`min_copper_edge_clearance`） | **0.2** | error |
| via ドリル（`min_through_hole_diameter`） | **0.3** | error |
| via アニュラリング（`min_via_annular_width`） | **0.076** | error |
| via 径（`min_via_diameter`） | **0.45** | error |
| pad→mask クリアランス | **0.0508**（2 mil） | — |
| pad→paste クリアランス | **0** | — |
| track-track 間隔（参考・推奨） | **0.127**（5 mil） | **warning** |

既存 via は φ0.3048 ドリル / φ0.6096 外径（アニュラリング 0.1524）なのでそのまま通る。

> **`pad_to_mask_clearance` の値についての明示的な逸脱**
> チームブリーフの指定値は 0.1016 mm（4 mil）だが、**0.0508 mm（2 mil）を採用する**。
> 理由 2 つ。(1) EasyEDA 側の `solderMaskExpansion.padTopExpan` が 2 mil で、
> 2026-08-16 に一度レビューを通った fab パッケージはこの値で出ている。ここを変えると
> 旧 Gerber とソルダーレジストが比較できなくなる。(2) ADS1299 は TQFP-64 0.5 mm ピッチ
> （パッド幅 0.28 mm・隙間 0.22 mm）で、片側 4 mil 拡張するとレジストダムが
> 0.22 − 0.2032 = **0.0168 mm** しか残らない。どの製造業者も保持できない寸法であり、
> DRC は「重なっていない」ので通してしまう＝黙って不良を出す設定になる。
> 2 mil なら 0.118 mm 残る。`solder_mask_min_width` を 0.0508 に設定し、
> 薄いダムが出たら DRC が実際に落ちるようにしてある。

## D. NPTH 6 穴

`kicad-cli pcb export drill --excellon-separate-th` の **NPTH ファイル**に 6 穴あること。
座標は旧 DRL（`cerelog_research/fab_2026-08-16/`）と **±2 µm** 一致。

| 穴 | KiCad 座標 [mm] | φ [mm] |
|---|---|---|
| USB-C ペグ ×2 | (176.861075, 108.097861) / (176.861075, 113.877885) | 0.700 |
| M2 取付 H1 | (123.048, 83.048) | 2.3876 |
| M2 取付 H2 | (176.9468, 83.048) | 2.3876 |
| M2 取付 H3 | (123.048, 121.9608) | 2.3876 |
| M2 取付 H4 | (176.9468, 121.9608) | 2.3876 |

さらに **各穴の切削円 ＋0.2 mm の内側に銅が 1 つも無いこと**
（トラック・via・パッド・ゾーンフィルの全て。Gerber を独立パーサで読んで判定する。
pcbnew の DRC 結果は使わない ＝ 二重チェック）。

PTH 穴と via の員数は S2 の実測から**変化しないこと**（PTH 16、via 238）。
ECO で via を足す場合はその増分だけを許容し、`gates/S4.json` に記録する。

## E. Gerber

`kicad-cli pcb export gerbers` ＋ `export drill` の出力が:

- **14 ファイル**（銅 4 ＋ レジスト 2 ＋ シルク 2 ＋ ペースト 2 ＋ 外形 1 ＋ `.gbrjob` 1 ＋ ドリル PTH/NPTH 2）
- 銅層 **4**（F.Cu / In1.Cu / In2.Cu / B.Cu）
- 外形 **61.8236 × 45.0088 mm（±0.01）**
- **独立パーサで解析できること**（KiCad に読み直させるのではなく、自前の RS-274X パーサで
  アパーチャと座標を解いて上の寸法・D. の銅無し判定を出す）

## F. BOM / CPL

- BOM の**全行に LCSC 番号**があること（空・不明が 1 つでもあれば fail）
- BOM の designator 集合 ⇄ CPL の designator 集合が**一致**
- 部品 **135**（＝契約と同じ。`H1`〜`H4` と USB-C ペグは両方から除外）
- ECO-2 / ECO-3 の置換が反映されていること（`data/parts_lcsc.csv` が正）

## G. 実装プレビュー

`kicad-cli pcb render`（または `export image`）で top / bottom の PNG を
`fab/preview_top.png` / `fab/preview_bottom.png` に保存すること。

---

## この文書が定義しないもの

- **回路の正しさ**。契約 `contract/netlist_contract.json` が正であることは前提で、
  本文書はそれと基板が一致することしか見ない
- **C_VREFP_10u の LCSC 番号 C13585 の実在性**。ECO-3 が「実装前に JLC API で裏取り必須、
  不能なら C15008」としている。裏取りは発注担当の作業で、ここでは
  `data/parts_lcsc.csv` に書かれた番号をそのまま通す（記録は残す）
- **FB5 が VDD_ESP(3.3V) と DVDD(2.5V) をフェライトで直結している件**（S2 の申し送り）。
  回路図＝契約がそう書いている以上、基板をそれに合わせるのが本パイプラインの仕事。
  設計判断は別件として `gates/design_observations.json` に残す
  → **この 1 点は決着した。下の追記を参照**

---

## 追記（2026-08-28）— 合否基準は 1 つも変えていない

凍結後に判明した事実の記録。**A〜G の基準・数値・許容リストには一切手を入れていない。**

**FB5 は疑義ではなく仕様だった。** 上の「この文書が定義しないもの」3 つめの括弧書き
「DVDD(2.5V)」は誤り。**DVDD は 3.3V 給電が正**（ADS1299 の DVDD 範囲 1.8〜3.6V 内、
ESP32 の 3.3V ロジックとも整合）。`PROJECT_STATUS.md` の「DVDD = 2.5V 共通」という記述のほうが
旧い。したがって FB5 pin1=`VDD_ESP` / pin2=`DVDD` は契約どおりで正しく、
**基板側の変更は不要**（S4 時点で既に一致。B 節の「差分 0」はこれを含めて満たしている）。

---

## 追記 2（2026-08-28）— 基準 **H** を追加した。A〜G は 1 文字も変えていない

カート投入後に **R_CC1（0603・高さ 0.45 mm）が USB-C レセプタクル J1 の本体外形の
内側に丸ごと入っている**ことが、コネクタの外形図から判明した。J1 のシェルは基板に
べたで着座するので、この基板は**組み立てられない**。A〜G は 32 項目すべて pass のまま
これを通した。

### なぜ A〜G はこれを見つけられなかったか

**`courtyards_overlap` を warning に落としたことが、そのまま穴になっていた。**
A 節の許容リストにある通り、EasyEDA 由来のコートヤードは実寸よりはるかに大きく
（1.0 × 0.5 mm の 0402 に対して 1.93 × 1.17 mm）、既存配置だけで 69 組が重なる。
だから warning に落とす判断自体は正しい ── 誤りは、**落とした代わりに本当の問いを
聞かなかったこと**。本当の問いはコートヤードではなく**本体（F.Fab 外形）**である。
コートヤードは「置けるか」の目安だが、F.Fab はベンダが描いた部品そのもので、
これが交わっていたら物理的に載らない。R_CC1 は J1 の F.Fab の **3.16 mm 内側**にいた。
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

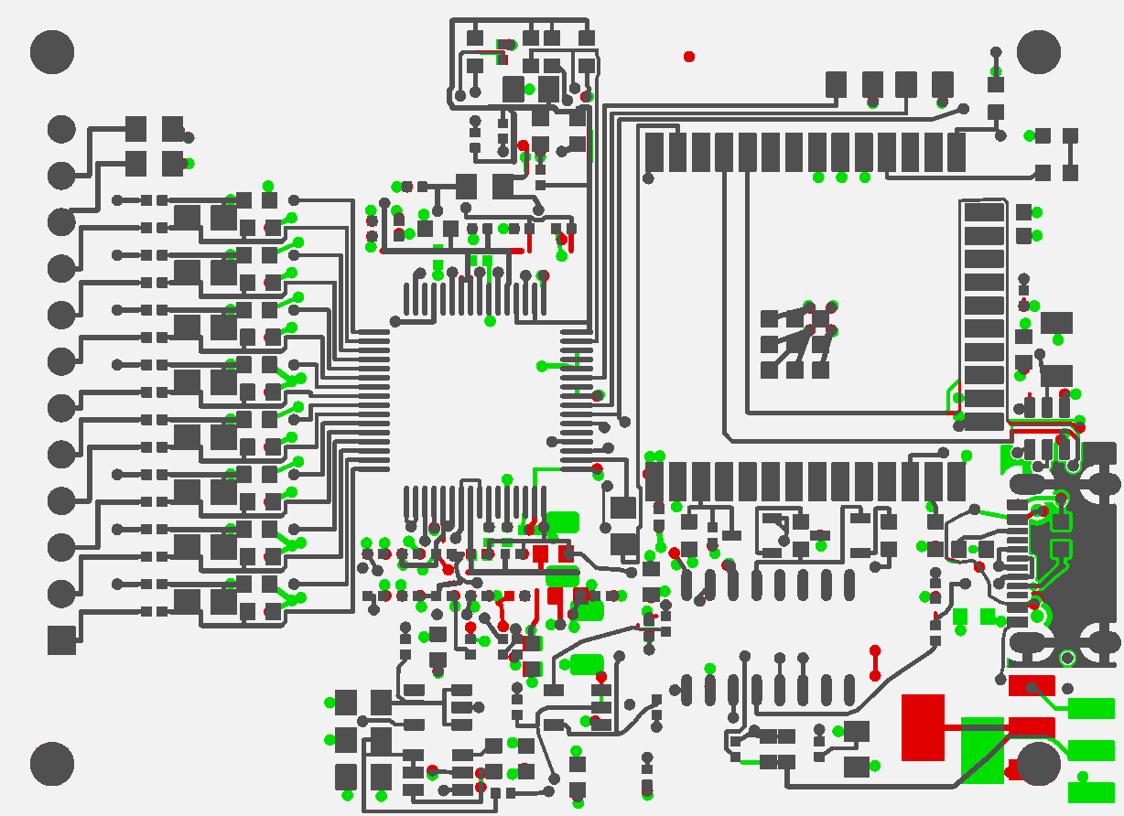
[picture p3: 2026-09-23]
reports/copper_xor_f_cu.png

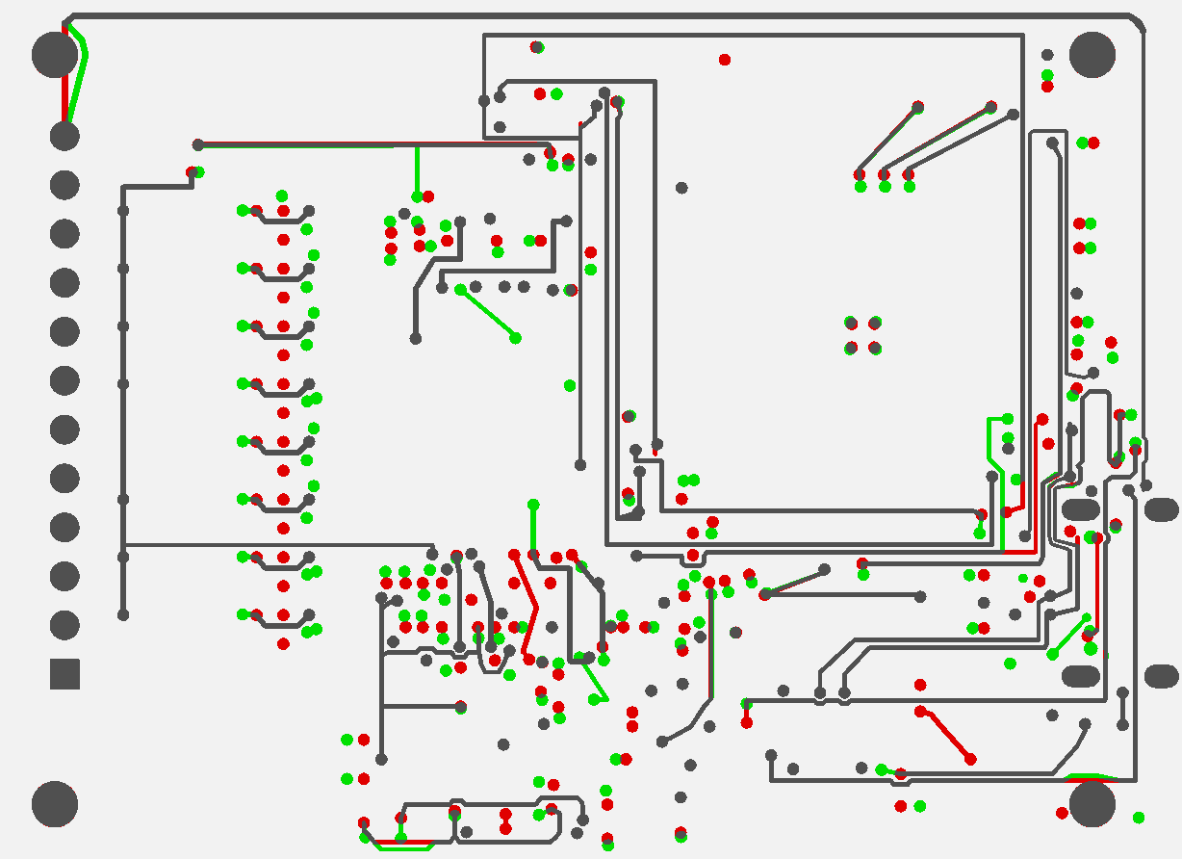
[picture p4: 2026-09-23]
reports/copper_xor_b_cu.png

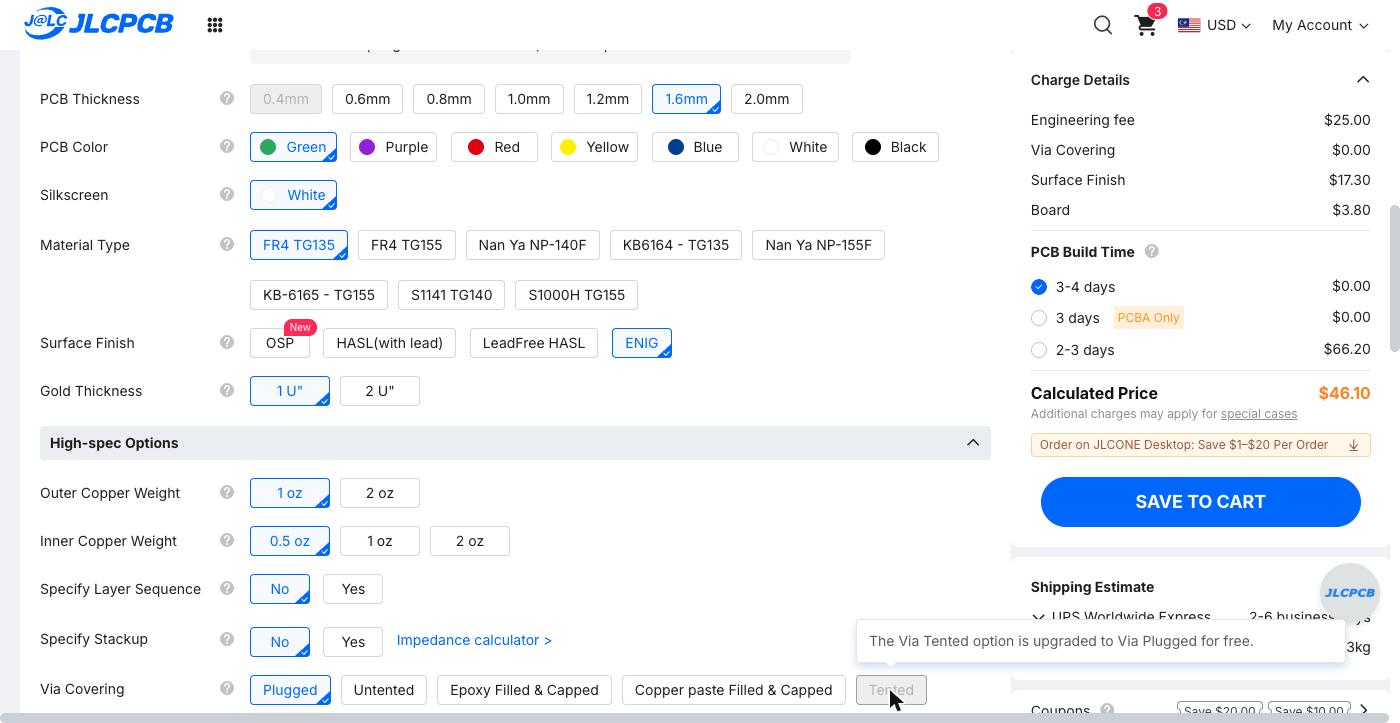
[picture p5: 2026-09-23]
fab/jlc_cart_2026-09-23_y9/02_via_tented_upgraded_to_plugged.jpg

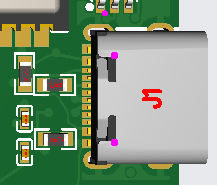
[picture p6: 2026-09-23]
fab/jlc_cart_2026-09-23_y9/09_placement_j1.png

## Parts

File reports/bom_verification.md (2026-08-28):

# Brain Canvas Rev.A — BOM 実体照合レポート（2026-08-28）

対象: `data/parts_lcsc.csv` / `board/Therapia_EEG-HRV.kicad_pcb`  
実装点数 **135** ・品番数 **30**  
判定: **NG 2** / **要確認 7** / OK 21

## 照合方法

各 C 番号を LCSC 商品ページ / EasyEDA 部品 API / JLCPCB partdetail の いずれか複数で取得し、data/parts_lcsc.csv の値・パッケージと kicad_pcb のフットプリント実測パッド寸法、および contract/netlist_from_kicad_pcb.json の実接続ネットに突合した。

出典 URL は各行に記録。取得できなかった項目は「取得不能」と明記し、推測では埋めていない。

## 結論（発注前に潰すべき項目）

| 優先 | 品番 | designator | 問題 | 推奨対処 |
|---|---|---|---|---|
| **1** | `C94221` | FB1–FB5 (5) | LCSC/JLC に**存在しない品番**。3 ソースで不存在を確認 | `C1017`（Sunlord GZ2012D601TF, L0805, **Basic**, 在庫 75,200）へ差し替え |
| **2** | `C72043` | D_LED (1) | 実体は緑 LED **Vf 3.3V**。3.3V GPIO + 330Ω では電流ほぼ 0 で点灯しない | `C72044`（Everlight 19-217/R6C 赤, Vf 1.95V, フットプリント・極性とも完全一致）へ差し替え。330Ω のまま約 4.1mA。詳細は末尾の追記を参照 |
| 3 | `C13585` | C_VREFP_10u (1) | CSV の MPN が誤り（実体は …K**B**H…, 50V） | **設計上は OK**。BOM の MPN 文字列のみ訂正。C15008 代替は不要 |
| 4 | `C1546` | C_AVDD1_10n, C_VREFP_10n (2) | designator は「10n」だが実装は 100pF | 10nF が正なら `C15195`(0402) 相当へ。現状維持なら designator をリネーム |
| 5 | `C369159` `C69932` `C701341` `C19619` | F1 / TPS72325 / U_MCU / TLV70025 | 在庫表示が薄い or ソース間で乖離 | JLC カート投入時に実数を確認。F1 の同一フットプリント代替は `C883122` |
| 6 | `C2840012` `C19619` `C72043` | J2 / TLV70025 / D_LED | CSV のパッケージ表記が実体と不一致 | **基板側フットプリントは全て正しい**。CSV のラベルのみ訂正 |

## NG（発注前に必ず修正）

### `C72043` — D_LED（1 点）

- **設計意図**: value='LED_Y'（黄）+ R_LED 330Ω で ESP32 GPIO(3.3V) から駆動
- **取得した実体**: 19-217/GHC-YR1S2/3T / Everlight Elec / LED0603-RD / LED 0603 / Emerald Green(518nm) / Vf 3.3V @20mA / 199mcd
- **判定理由**: 実体は Emerald Green・**Vf 3.3V**。3.3V GPIO − Vf3.3V = 0V となり 330Ω では電流がほぼ流れず点灯しない/極端に暗い。また BOM value 'LED_Y'（黄）と実体（緑）が不一致。ECO-2#9 で 10kΩ→330Ω に変えた前提は Vf≈2V の赤/黄 LED。
- 補足: 色（緑）と Vf 3.3V は LCSC ページ・JLC partdetail の 2 ソースで一致。JLC 実装区分は 3 URL とも表示されず取得不能。
- **推奨代替**: `C72044` 19-217/R6C-AL1M2VY/3T / LED0603-RD / LED 0603 / 赤 617.5nm / Vf 1.95V @5mA / 11.5-28.5mcd / 120deg / 60mW / JLC **Extended** / 在庫 215,065
  - D_LED 第 1 候補。現フットプリントと**パッケージ名が完全一致**（LED0603-RD）で、ピン生データも pin1='C' / pin2='A'（C72043 と同一シリーズ・同一ライブラリ）。3.3V - 1.95V = 1.35V / 330Ω = 約 4.1mA。在庫は EasyEDA API 215,065（SZ 902,100）に対し LCSC 商品ページは 'Not available now' 表示で食い違う。
  - 出典: https://www.lcsc.com/product-detail/C72044.html , https://jlcpcb.com/partdetail/EverlightElec-19_217_R6C_AL1M2VY3T/C72044 , https://easyeda.com/api/products/C72044/components
- **推奨代替**: `C72038` 19-213/Y2C-CQ2R2L/3T(CY) / LED0603-RD-YELLOW / LED 0603 / 黄 / Vf 1.7-2.3V @20mA / 90-180mcd / JLC **Extended** / 在庫 70,862
  - D_LED 第 2 候補。ピン生データは pin1='C' / pin2='A' で**現基板の極性と一致**（`P~show~1~1~...C~start` / `P~show~1~2~...A~end`）。BOM の value 'LED_Y'（黄）とも色が一致し、輝度は C72044 より高い。ただしパッケージ名は 'LED0603-RD-**YELLOW**' で現フットプリント名と厳密には別名（0603 ランド自体は同等とみられるがカート投入時に要プレビュー確認）。Vf 2.0V 換算で (3.3-2.0)/330 = 約 3.9mA。
  - 出典: https://jlcpcb.com/partdetail/C72038 , https://easyeda.com/api/products/C72038/components
- 出典: https://www.lcsc.com/product-detail/C72043.html , https://jlcpcb.com/partdetail/EverlightElec-19_217_GHC_YR1S23T/C72043 , https://easyeda.com/api/products/C72043/components
- **【確定】この推奨は覆った。** カート投入時（2026-08-28）に `C72044` / `C72038` とも JLC 実装在庫 0。**採用は `C84268`**（末尾「カート投入時の差替 2026-08-28」）。

### `C94221` — FB1, FB2, FB3, FB4, FB5（5 点）

- **設計意図**: FB_600R 600Ω@100MHz フェライトビーズ 0805 x5
- **取得した実体**: 取得不能（部品が存在しない） / - / - / -
- **判定理由**: **この C 番号は LCSC/JLC に存在しない**（3 ソースで不存在を確認）。このまま発注すると JLC 側で部品が引けない。正しい品番は C1017。
- 補足: LCSC 商品ページ HTTP 404 / EasyEDA API 'Component not found' 404 / JLC partdetail は空欄（No specifications available）。3 ソースとも不存在。CSV が意図した GZ2012D601TF の正しい品番は C1017。
- **推奨代替**: `C1017` GZ2012D601TF / L0805 / フェライトビーズ 600Ω@100MHz +-25% / 定格 500mA / DCR 300mΩ / 0805 / JLC **Basic** / 在庫 75,200
  - C94221 が意図していた GZ2012D601TF の正しい品番。EasyEDA パッケージ名 'L0805' は KiCad 側フットプリントと完全一致。
  - 出典: https://jlcpcb.com/partdetail/Sunlord-GZ2012D601TF/C1017 , https://easyeda.com/api/products/C1017/components
- 出典: https://www.lcsc.com/product-detail/C94221.html , https://easyeda.com/api/products/C94221/components , https://jlcpcb.com/partdetail/C94221

## 要確認

### `C13585` — C_VREFP_10u（1 点）

- **設計意図**: ECO-3#12: 10uF 1206 25V（VREFP=4.5V の DC バイアス減衰対策）
- **取得した実体**: CL31A106KBHNNNE / Samsung Electro-Mechanics / C1206 / 10uF / 50V / X5R / +-10% / 1206
- **判定理由**: 【裏取り完了】実体は CL31A106K**B**HNNNE = 10uF **50V** X5R 1206。CSV の MPN 'CL31A106KAHNNNE' は誤り。値・パッケージ・材質は意図を満たし、50V なので 25V 品より DC バイアス減衰が小さく設計上はむしろ良好。→ C15008 での代替は不要。BOM の MPN 文字列のみ訂正。
- 補足: CSV の MPN 'CL31A106KAHNNNE' は誤り。LCSC ページ・JLC partdetail・EasyEDA API の 3 ソースとも 'CL31A106K**B**HNNNE / 50V'。在庫は LCSC ページ 917,300 に対し EasyEDA API 0/0 で食い違う。
- 出典: https://www.lcsc.com/product-detail/C13585.html , https://jlcpcb.com/partdetail/C13585 , https://easyeda.com/api/products/C13585/components

### `C1546` — C_AVDD1_10n, C_VREFP_10n（2 点）

- **設計意図**: designator は C_AVDD1_10n / C_VREFP_10n（= 10nF を示唆）
- **取得した実体**: 0402CG101J500NT / FH (Fenghua) / C0402 / 100pF / 50V / C0G(NP0, 型番 CG) / +-5% / 0402
- **判定理由**: 実体は 100pF C0G。ECO-2#7 が C_NR で修正したのと同型の 『名前は 10n・中身は 100pF』の不整合が 2 個所残っている。AVDD/VREFP には別途 100nF+10uF が並列なので実害は小さいが意図確認を推奨。
- 出典: https://easyeda.com/api/products/C1546/components

### `C19619` — TLV70025（1 点）

- **設計意図**: TLV70025 +2.5V LDO / CSV package='SOT-353'
- **取得した実体**: TLV70025DDCR / Texas Instruments / SOT-23-5_L3.0-W1.7-P0.95-LS2.8-BR / LDO +2.5V 固定 / 200mA / SOT-23-5(TI DDC)
- **判定理由**: 実体は SOT-23-5（TI DDC パッケージ）。PCB フットプリントは SOT-23-5_L3.0-W1.7-P0.95-LS2.8-BR で **正しい**（EasyEDA パッケージ名と完全一致）。CSV の 'SOT-353' 表記のみ誤り。在庫 1,480-2,186 でやや薄い。
- 補足: LCSC ページ 1,480 / EasyEDA API 2,186（SZ 1,577）。CSV の package 'SOT-353' は誤りで実体は SOT-23-5。
- 出典: https://www.lcsc.com/product-detail/C19619.html , https://easyeda.com/api/products/C19619/components

### `C2840012` — J2（1 点）

- **設計意図**: CSV value='Header_2x6' / package='HDR-2.54-2x6'
- **取得した実体**: PZ254V-11-12P / XFCN / HDR-TH_12P-P2.54-V-M / ピンヘッダ 1 列 x 12P / 2.54mm / スルーホール垂直 / 250V 3A
- **判定理由**: 実体は **1 列 x 12 ピン**（row=1）。PCB フットプリント HDR-TH_12P-P2.54-V-M も 12 パッド全て y=0 の 1 列なので**部品と基板は整合**。CSV のラベル表記のみ誤り。
- 補足: 1 列 12 ピン（2x6 ではない）。LCSC ページ・EasyEDA API とも row=1。
- 出典: https://www.lcsc.com/product-detail/C2840012.html , https://easyeda.com/api/products/C2840012/components

### `C369159` — F1（1 点）

- **設計意図**: Polyfuse hold 500mA / 1206（USB_VBUS_RAW→USB_5V）
- **取得した実体**: JK-NSMD050-13.2V / JK (Jinrui) / F1206 / PPTC リセッタブルヒューズ / hold 500mA / trip 1A / 13.2V / 1206
- **判定理由**: 仕様（500mA hold / 1206）は意図と一致し F1206 フットプリントとも整合。ただし LCSC 商品ページが 'Not available now' 表示で在庫要確認。
- 補足: LCSC 商品ページは 'Not available now'。EasyEDA API は 6,160/53,060。
- **代替候補**: `C883122` BSMD1206-050-6V / F1206 / PPTC リセッタブルヒューズ hold 500mA / 6V / 1206 / JLC **Extended** / 在庫 3,420
  - F1 の同一フットプリント代替。定格電圧は 13.2V→6V に下がる点に注意。
- 出典: https://www.lcsc.com/product-detail/C369159.html , https://easyeda.com/api/products/C369159/components
- **【確定】** カート投入時（2026-08-28）に `C369159` は JLC 実装在庫 0。**採用は `C43379`**（13.2V を維持。末尾「カート投入時の差替 2026-08-28」）。

### `C69932` — TPS72325（1 点）

- **設計意図**: TPS72325 -2.5V LDO / SOT-23-5
- **取得した実体**: TPS72325DBVR / Texas Instruments / SOT-23-5_L3.0-W1.7-P0.95-LS2.8-BR / 負電圧 LDO -2.5V / 200mA / 超低ノイズ 60uVrms / SOT-23-5
- **判定理由**: MPN・パッケージ一致（EasyEDA パッケージ名が KiCad と完全一致）。LCSC 在庫 0（SZ 3,843）で在庫リスクあり。
- 補足: LCSC ページ 7,086 / EasyEDA API 0（SZ 3,843）。
- 出典: https://www.lcsc.com/product-detail/C69932.html , https://easyeda.com/api/products/C69932/components

### `C701341` — U_MCU（1 点）

- **設計意図**: ESP32-WROOM-32E-N4 / SMD モジュール
- **取得した実体**: ESP32-WROOM-32E-N4 / Espressif / WIFI-SMD_ESP32-WROOM-32E / ESP32 モジュール 4MB flash / SMD 25.5x18mm
- **判定理由**: MPN・パッケージ一致（47 パッド = 38 ピン + サーマル 9 分割）。在庫が LCSC ページ 29,577 と EasyEDA API 6 で大きく乖離。要カート確認。
- 補足: LCSC ページ 29,577 / EasyEDA API 6（SZ 916）。乖離が大きく要カート確認。
- 出典: https://www.lcsc.com/product-detail/C701341.html , https://easyeda.com/api/products/C701341/components

## 全品番一覧

| 判定 | C番号 | designator（数） | 取得した MPN / メーカー | 取得したスペック | 取得したパッケージ | KiCad フットプリント | JLC 区分 | LCSC 在庫 | SZLCSC 在庫 |
|---|---|---|---|---|---|---|---|---|---|
| **NG** | `C72043` | D_LED (1) | 19-217/GHC-YR1S2/3T / Everlight Elec | LED 0603 / Emerald Green(518nm) / Vf 3.3V @20mA / 199mcd | `LED0603-RD` | `LED0603-RD` | 取得不能 | 54,300 | 1,440,000 |
| **NG** | `C94221` | FB1, FB2, FB3, FB4, FB5 (5) | 取得不能（部品が存在しない） / - | - | `-` | `L0805` | 存在しない | 取得不能 | 取得不能 |
| 要確認 | `C13585` | C_VREFP_10u (1) | CL31A106KBHNNNE / Samsung Electro-Mechanics | 10uF / 50V / X5R / +-10% / 1206 | `C1206` | `Capacitor_SMD:C_1206_3216Metric` | Basic | 917,300 | 0 |
| 要確認 | `C1546` | C_AVDD1_10n, C_VREFP_10n (2) | 0402CG101J500NT / FH (Fenghua) | 100pF / 50V / C0G(NP0, 型番 CG) / +-5% / 0402 | `C0402` | `C0402` | Basic | 558,700 | 1,401,500 |
| 要確認 | `C19619` | TLV70025 (1) | TLV70025DDCR / Texas Instruments | LDO +2.5V 固定 / 200mA / SOT-23-5(TI DDC) | `SOT-23-5_L3.0-W1.7-P0.95-LS2.8-BR` | `SOT-23-5_L3.0-W1.7-P0.95-LS2.8-BR` | Extended | 2,186 | 1,577 |
| 要確認 | `C2840012` | J2 (1) | PZ254V-11-12P / XFCN | ピンヘッダ 1 列 x 12P / 2.54mm / スルーホール垂直 / 250V 3A | `HDR-TH_12P-P2.54-V-M` | `HDR-TH_12P-P2.54-V-M` | Extended | 28,720 | 取得不能 |
| 要確認 | `C369159` | F1 (1) | JK-NSMD050-13.2V / JK (Jinrui) | PPTC リセッタブルヒューズ / hold 500mA / trip 1A / 13.2V / 1206 | `F1206` | `F1206` | Extended | 6,160 | 53,060 |
| 要確認 | `C69932` | TPS72325 (1) | TPS72325DBVR / Texas Instruments | 負電圧 LDO -2.5V / 200mA / 超低ノイズ 60uVrms / SOT-23-5 | `SOT-23-5_L3.0-W1.7-P0.95-LS2.8-BR` | `SOT-23-5_L3.0-W1.7-P0.95-LS2.8-BR` | Extended | 7,086 | 3,843 |
| 要確認 | `C701341` | U_MCU (1) | ESP32-WROOM-32E-N4 / Espressif | ESP32 モジュール 4MB flash / SMD 25.5x18mm | `WIFI-SMD_ESP32-WROOM-32E` | `WIFI-SMD_ESP32-WROOM-32E` | Extended | 29,577 | 916 |
| OK | `C108573` | LM2664 (1) | LM2664M6X/NOPB / Texas Instruments | スイッチトキャパシタ電圧反転 / 1.8-5.5V in / 40mA / SOT-23-6 | `SOT-23-6_L2.9-W1.6-P0.95-LS2.8-BR` | `SOT-23-6_L2.9-W1.6-P0.95-LS2.8-BR` | Extended | 49,955 | 1,620 |
| OK | `C12530` | C_NLDO_OUT (1) | CL05A225MQ5NSNC / Samsung Electro-Mechanics | 2.2uF / 6.3V / X5R / +-20% / 0402 | `C0402` | `C0402` | Basic | 5,406,800 | 282,800 |
| OK | `C15008` | C_VCAP1 (1) | CL31A107MQHNNNE / Samsung Electro-Mechanics | 100uF / 6.3V / X5R / +-20% / 1206 | `C1206` | `Capacitor_SMD:C_1206_3216Metric` | Basic | 2,054,820 | 107,937 |
| OK | `C15195` | C_NR (1) | CL05B103KB5NNNC / Samsung Electro-Mechanics | 10nF / 50V / X7R / +-10% / 0402 | `C0402` | `C0402` | Basic | 4,411,600 | 266,400 |
| OK | `C1525` | C_3V3_H ほか (28) | CL05B104KO5NNNC / Samsung Electro-Mechanics | 100nF / 16V / X7R / +-10% / 0402 | `C0402` | `C0402` | Basic | 869,375 | 4,941,800 |
| OK | `C1588` | C_CM1N ほか (16) | CL10B102KB8NNNC / Samsung Electro-Mechanics | 1nF / 50V / X7R(型番 B) / +-10% / 0603 | `C0603` | `C0603` | Basic | 673,512 | 123,000 |
| OK | `C17477` | R_MISO, R_MOSI, R_SCLK, R_SRB_SER (4) | 0805W8F0000T5E / UNI-ROYAL | 0Ω ジャンパ / 0805 | `R0805` | `R0805` | Basic | 433,289 | 2,148,400 |
| OK | `C17514` | R_BIAS_FB, R_BIAS_SER (2) | 0805W8F1004T5E / UNI-ROYAL | 1MΩ / +-1% / 0805 | `R0805` | `R0805` | Basic | 203,700 | 872,900 |
| OK | `C19702` | C_3V3_B ほか (12) | CL10A106KP8NNNC / Samsung Electro-Mechanics | 10uF / 10V / X5R / +-10% / 0603 | `C0603` | `C0603` | Basic | 6,738,300 | 0 |
| OK | `C2146` | Q_EN, Q_IO0 (2) | S8050 J3Y(RANGE:200-350) / CJ (Changjiang) | NPN トランジスタ / hFE 200-350 / SOT-23-3 | `SOT-23-3_L3.0-W1.7-P0.95-LS2.9-BR` | `SOT-23-3_L3.0-W1.7-P0.95-LS2.9-BR` | Basic | 451,617 | 508,750 |
| OK | `C23138` | R_LED (1) | 0603WAF3300T5E / UNI-ROYAL | 330Ω / +-1% / 0603 | `R0603` | `R0603` | Basic | 470,600 | 359,100 |
| OK | `C23186` | R_CC1, R_CC2 (2) | 0603WAF5101T5E / UNI-ROYAL | 5.1kΩ / +-1% / 0603 | `R0603` | `R0603` | Basic | 897,098 | 1,796,800 |
| OK | `C237168` | C_DIF1 ほか (8) | 0805N103J500CT / Walsin | 10nF / 50V / NP0 / +-5% / 0805 | `C0805` | `C0805` | Extended | 152,260 | 5,820 |
| OK | `C25744` | R_IN1N ほか (16) | 0402WGF1002TCE / UNI-ROYAL | 10kΩ / +-1% / 0402 | `R0402` | `R0402` | Basic | 235,900 | 2,745,500 |
| OK | `C25804` | R_CS_UP ほか (11) | 0603WAF1002T5E / UNI-ROYAL | 10kΩ / +-1% / 0603 | `R0603` | `R0603` | Basic | 8,999,650 | 0 |
| OK | `C2765186` | J1 (1) | TYPE-C 16PIN 2MD(073) / SHOU HAN | USB Type-C レセプタクル 16P / SMD + 位置決めペグ / 5V 5A | `USB-C-SMD_TYPE-C-16PIN-2MD-073` | `USB-C-SMD_TYPE-C-6PIN-2MD-073` | Extended | 940,940 | 取得不能 |
| OK | `C476817` | U_ADS (1) | ADS1299IPAGR / Texas Instruments | 24bit 8ch 生体電位 AFE / TQFP-64(10x10) / MSL3 / $60.31 | `TQFP-64_L10.0-W10.0-P0.50-LS12.0-TL` | `TQFP-64_L10.0-W10.0-P0.50-LS12.0-TL` | Extended | 3,126 | 取得不能 |
| OK | `C52923` | C_3V3_IN ほか (10) | CL05A105KA5NQNC / Samsung Electro-Mechanics | 1uF / 25V / X5R / +-10% / 0402 | `C0402` | `C0402` | Basic | 3,790,400 | 3,663,900 |
| OK | `C6186` | AMS1117 (1) | AMS1117-3.3 / Advanced Monolithic Systems | LDO 3.3V fixed, SOT-223-3 | `SOT-223-3_L6.5-W3.4-P2.30-LS7.0-BR` | `SOT-223-3_L6.5-W3.4-P2.30-LS7.0-BR` | Basic | 222,228 | 113,340 |
| OK | `C7519` | D_ESD (1) | USBLC6-2SC6 / STMicroelectronics | USB ESD 保護ダイオードアレイ, SOT-23-6 | `SOT-23-6_L2.9-W1.6-P0.95-LS2.8-BL` | `SOT-23-6_L2.9-W1.6-P0.95-LS2.8-BL` | Extended | 28,668 | 3,590 |
| OK | `C84681` | U_USB (1) | CH340C / WCH | USB-UART ブリッジ / 内蔵クロック（水晶不要）/ SOP-16 | `SOP-16_L10.0-W3.9-P1.27-LS6.0-BL` | `SOP-16_L10.0-W3.9-P1.27-LS6.0-BL` | Extended | 61,409 | 63,893 |

## 在庫リスク順位

在庫はソース間で食い違うことがあるため、最終確定は JLC カート投入時とする。以下は「発注前に実数を確認すべき」順。

| 順位 | 品番 | designator | 取得できた在庫 | JLC 区分 | リスク内容 | 代替 |
|---|---|---|---|---|---|---|
| 1 | `C94221` | FB1–FB5 | — | 存在しない | 品番自体が引けない（在庫以前の問題） | `C1017` (Basic, 75,200) |
| 2 | `C701341` | U_MCU | LCSC ページ 29,577 / API **6** | Extended | ソース間の乖離が最大。ESP32 モジュールは代替が効きにくい | 同等品は要検討 |
| 3 | `C69932` | TPS72325 | LCSC ページ 7,086 / API **0**（SZ 3,843） | Extended | 負電圧 LDO は代替品が少ない。欠品時は基板が動かない | ピン互換の TPS723xx 系を要調査 |
| 4 | `C13585` | C_VREFP_10u | LCSC ページ 917,300 / API **0/0** | Basic | ソース間の乖離。Basic なので JLC 側は通常確保 | `C15008`(100uF 6.3V 1206) で代替可 |
| 5 | `C369159` | F1 | LCSC ページ **Not available now** / API 6,160 | Extended | 商品ページが在庫なし表示 | `C883122`（F1206 同一, 6V 定格に低下） |
| 6 | `C19619` | TLV70025 | 1,480〜2,186 | Extended | 絶対数が少ない。10 台分なら足りる | +2.5V 200mA SOT-23-5 LDO を要調査 |
| 7 | `C476817` | U_ADS | 3,126 | Extended | 単価 $60.31 と高額。数量確保より価格インパクト大 | 代替不可（設計の中核） |
| 8 | `C108573` | LM2664 | LCSC ページ 49,955 / API **0**（SZ 1,620） | Extended | ソース間の乖離 | — |

## JLC Extended 部品（手数料対象）

現 BOM の Extended は **11 品番**: `C237168`(C_DIF1), `C7519`(D_ESD), `C369159`(F1), `C2765186`(J1), `C2840012`(J2), `C108573`(LM2664), `C19619`(TLV70025), `C69932`(TPS72325), `C476817`(U_ADS), `C701341`(U_MCU), `C84681`(U_USB)

推奨差し替え（`C94221`→`C1017`, `C72043`→`C2286`）はいずれも Basic 品なので、Extended 品番数は増えない。`C369159`→`C883122` は Extended のままで増減なし。

## BOM 以外に気づいた点（参考・lead 判断用）

> 注: `contract/netlist_from_kicad_pcb.json` は 13:45 のスナップショットで、その後 `board/Therapia_EEG-HRV.kicad_pcb` が 16:46 に更新された（並行作業）。以下は **16:47 に基板ファイルを直接読み直した結果**に基づく。

- **ECO-1 は PCB に反映済み（再確認して訂正）**: 本レポート初版では「TPS72325 の pin3(EN) が `GND` のままで B1 致命バグが残存」と書いたが、これは 13:45 のネットリストに基づく古い所見だった。現在の基板ファイルでは **pin3 = `V_NLDO_IN`**（pin1=GND / pin2=V_NLDO_IN / pin4=TPS_NR / pin5=AVSS）で、ECO-1#1 は適用済み。
- **ECO-1/ECO-3 の新設・変更部品も配置済み（同上）**: `C_VCAP1_H`(VCAP1-AVSS)、`C_VCAP2`(VCAP2-AVSS)、`C_VCAP3`(VCAP3-AVSS)、`C_VCAP3_H`(VCAP3-AVSS) の 4 点が `C0402` で配置・結線済み。`C_VCAP1` と `C_VREFP_10u` も `C_1206_3216Metric` に差し替わっており ECO-3 の 1206 化も完了している。BOM 135 点と基板の点数は整合する。
- **D_LED まわりは未変更**: `D_LED` pad1=`GND` / pad2=`LED_A`、`R_LED` pad1=`STATUS_LED_DRV` / pad2=`LED_A` で、上記 LED の判定はそのまま有効。
- **DVDD は +3.3V 給電**: FB5 が `VDD_ESP → DVDD`。`08_simplified_power_design.md` の「AVDD と DVDD を共通 +2.5V」という記述と食い違う。実回路の 3.3V は ADS1299 の DVDD 定格範囲内で、ESP32 の 3.3V ロジックとも整合するため 回路としては妥当。ドキュメント側が古い。
- **フェライトビーズの DCR 前提が古い**: `08_simplified_power_design.md` は BLM18PG600SN1D（DCR 38mΩ / 2.5A）前提で電圧降下 5.7mV としているが、実体の GZ2012D601TF は **DCR 300mΩ / 定格 500mA**。FB3 は ESP32 系 80–240mA を通すため 降下は 24–72mV（想定の 4〜12 倍）。Rev.A は許容範囲だが、余裕を取るなら低 DCR 品を検討。
- **ADS1299 PAG にサーマルパッドは無い**: KiCad フットプリントは 64 パッドのみで実体と整合。`08_simplified_power_design.md` の「ADS1299 の thermal pad 直下に 9 個の via」は成立しない。
- **USB-C のフットプリント名**: KiCad 側 `USB-C-SMD_TYPE-C-6PIN-2MD-073` は EasyEDA 側 `…-16PIN-…` の名称欠落。パッド実体（12 SMD + 4 TH）は正しく、ピン割当も EasyEDA シンボルの pinName と netlist が一致しているため実害なし。

## 変更しなかったもの

本レポートは調査のみ。`data/parts_lcsc.csv`・`board/` は一切編集していない。差し替えの反映は lead 判断とする。

---

# 追記（2026-08-28、追加調査）

## 1. D_LED の代替を確定

### 前提：現基板側の極性

- フットプリント: `ProPrj_The-easyedapro:LED0603-RD`
- パッド実測: pad1/pad2 とも 0.8x0.8mm 角、x=-0.749 / +0.749mm（0603 ランド）
- **極性: pad1 = C（カソード）→ GND / pad2 = A（アノード）→ LED_A**
- 根拠: contract/netlist_easyeda_api_2026-08-28.tsv の D_LED 行が pinName を保持: `D_LED 1 C GND` / `D_LED 2 A LED_A`

シルクの向きではなく **EasyEDA シンボルの pinName** を根拠にした（J1 の ピン割当を確定したのと同じ方法）。`pinNumber` はライブラリ内連番でデータシートと一致しないことがあるため単独では使わない。

### 候補の比較

| | C番号 | MPN / 色 | EasyEDA パッケージ名 | ピン番号→名 | Vf | 330Ω・3.3V での電流 | JLC 区分 | 在庫(LCSC / SZLCSC) | 判定 |
|---|---|---|---|---|---|---|---|---|---|
| **第1候補** | `C72044` | 19-217/R6C-AL1M2VY/3T / 赤 617.5nm | `LED0603-RD` **完全一致** | **1=C, 2=A**（現基板と一致） | 1.95V @5mA | **約 4.1mA** | Extended | 215,065 / 902,100 | **採用推奨** |
| **第2候補** | `C72038` | 19-213/Y2C-CQ2R2L/3T(CY) / 黄 | `LED0603-RD-YELLOW`（別名） | **1=C, 2=A**（現基板と一致） | 1.7–2.3V @20mA | 約 3.9mA | Extended | 70,862 / 187,040 | 採用可 |
| 不採用 | `C2286` | KT-0603R / 赤 645nm | `LED-SMD_L1.6-W0.8-R-RD`（別名） | **1=A, 2=K**（**反転**） | 1.8–2.4V | 約 3.9mA | Basic | 624,750 / 0 | **NG（逆実装になる）** |
| 不採用 | `C183844` | 19-217/G7C-AM1N2B/3T / 黄緑 | `LED0603-RD` 一致 | 取得不能 | 取得不能 | — | Extended | 2,920 / 540 | 非推奨（在庫薄） |

### 判定理由

**`C72044` を第 1 候補とする。** 現在の `C72043` と同じ Everlight 19-217 シリーズ・同じ EasyEDA ライブラリの赤バリアントで、パッケージ名が `LED0603-RD` と完全一致する。ピン生データも `P~show~1~**1**~...~**C**~end~...` / `P~show~1~**2**~...~**A**~start~...` で pin1=カソード・pin2=アノード、現基板の pad1=GND(カソード) と一致するため、**C 番号の差し替えだけで済み、基板の銅箔も配線も触らなくてよい**。Vf 1.95V に対し (3.3−1.95)/330 = 約 4.1mA で、依頼の 3〜4mA 帯に収まる。

JLC 区分は Extended だが、差し替え前の `C72043` も同シリーズで、同ページに Basic バッジが出ていないため区分は実質変わらないと見込まれる（`C72043` の区分は 3 URL とも表示されず取得不能のままなので、断定はしない）。

**`C72038`（黄）を第 2 候補とする。** ピン番号→名は `1=C / 2=A` で現基板と一致し、BOM の value `LED_Y`（黄）とも色が揃う。輝度も 90–180mcd@20mA と `C72044` の 11.5–28.5mcd@5mA より高く、ステータス表示としては見やすい。唯一の引っかかりはパッケージ名が `LED0603-RD-YELLOW` と別名である点で、0603 ランド自体は同等と見られるが名称一致の条件を厳密には満たさないため第 2 候補とした。採用する場合はカート投入時に JLC のプレビューで外形と向きを確認すること。

**`C2286`（前回の推奨）は撤回する。** EasyEDA シンボルのピン生データを読むと `0~1~-5~0~**A**~end~~~#800^^0~9~-9~0~**1**~start` と `0~**K**~start~~~#800^^0~-9~-9~0~**2**~end` で、**A=pin1 / K=pin2**。現基板は pad1 がカソードなので、そのまま置換すると LED が逆実装になる。Basic かつ在庫潤沢という利点はあるが、極性が合わないので採用しない。

## 2. C1017（GZ2012D601TF）のフットプリント整合

- 基板側: `ProPrj_The-easyedapro:L0805（FB1-FB5 の 5 点すべて）`
- パッド実測: pad1/pad2 とも 1.1325 x 1.377mm、x=-0.966 / +0.966mm。内側ギャップ 0.8mm / 外形スパン 3.065mm / パッド幅 1.377mm
- 部品側: C1017 の EasyEDA パッケージ名は `L0805`（JLC partdetail の表記は `0805`）
- **判定: OK**
- 理由: フットプリント名が `L0805` で完全一致。MPN の 'GZ2012' は 2012 メートル法 = 0805 インチで、パッド幅 1.377mm > 本体幅 1.25mm、スパン 3.065mm > 本体長 2.0mm とランドが本体を包含する。2 端子無極性なので向きの検討は不要。

`grep -o 'footprint "[^"]*"'` の結果でも `ProPrj_The-easyedapro:L0805` はちょうど 5 個で、FB1–FB5 の 5 点と一致する。他の 0805 系（`C0805` 8 個・`R0805` 6 個）とは別フットプリントとして分かれており、取り違えは起きていない。

---

# 追記 2（2026-08-28、追加調査その 2）

## 3. BIAS 帰還用 1.5nF 0402（ECO-5）

### 現基板の該当箇所

- `R_BIAS_FB`: 1MΩ 0805 (C17514) が BIAS_INV <-> BIAS_OUT_INT を橋渡し
- `C_BIAS_INV`: 現在 100nF (C1525) が BIAS_INV -> GND、フットプリント C0402
- `ADS1299_pinName`: pin61=BIASINV / pin63=BIASOUT（contract TSV の pinName で確認）
- ECO-5 でこの `C_BIAS_INV` の pad2 を `GND` から `BIAS_OUT_INT` に移し 1.5nF にすると、TI 推奨の 1MΩ ∥ 1.5nF になる。極は 1/(2*pi*1M*1.5n) = 約 106Hz（TI 推奨値）。

### 候補

| | C番号 | MPN / メーカー | EasyEDA パッケージ | スペック | JLC 区分 | 在庫(LCSC / SZLCSC) |
|---|---|---|---|---|---|---|
| **第1候補** | `C23967` | CL05B152KB5NNNC / Samsung | `C0402` **一致** | 1.5nF **50V X7R ±10%** | Extended | 60,236 / 21,600 |
| **第2候補** | `C284989` | 0402B152K500NT / FH(風華) | `C0402` **一致** | 1.5nF 50V ±10%(K) | Extended | 19,300 / 95,000 |
| 不採用 | `C281752` | CC0402JRX7R9BB152 / YAGEO | `C0402` | 1.5nF X7R | Extended | **0 / 0** |
| 参考(C0G) | `C52037853` | CGA0402C0G152J500GT / HRE | `0402` | 1.5nF 50V **C0G** ±5% | 取得不能 | 2,250 / — |

### 判定理由

**Basic は選べない。** JLC Basic に 1.5nF 0402 は存在しない。検索した 1.5nF 0402 は Samsung/FH/YAGEO/Walsin/KEMET/AVX/Vishay/Meritek いずれも Extended。1nF に落とす案（C14442）も Extended なので手数料回避にならない。 したがって値を妥協する理由がなく、TI 推奨の 1.5nF をそのまま使うのが合理的。

**第 1 候補は `C23967`（Samsung CL05B152KB5NNNC）。** JLC partdetail が 「1.5nF 50V X7R ±10% 0402」と明示しており誘電体まで確定できる唯一の候補で、EasyEDA パッケージ名 `C0402` は現フットプリント `ProPrj_The-easyedapro:C0402` と完全一致する。在庫も 60,236 / 21,600 と十分。

**第 2 候補は `C284989`（FH 0402B152K500NT）。** パッケージ名 `C0402` 一致、SZLCSC 在庫 95,000 と潤沢で、FH は既に `C1546` で BOM に入っているメーカー。ただし誘電体の明記が取得できなかった（型番の 'B' は FH の X7R 系だが未裏取り）ので第 2 候補とした。なお EasyEDA API が返す「Voltage Rated 500V」は型番 '...500NT' の誤パースで、同じ表記体系の `C1546`（0402CG101J500NT）が 50V と確認済みなので 50V と判断している。

**材質について。** C0G が理想ではあるが、X7R でも実害は小さいと判断した。この C は 1MΩ と並列で BIASINV(加算節点) と BIASOUT の間に入り両端の DC 電位差がほぼ 0V なので、X7R の弱点である DC バイアス容量減衰が効かない。残る誘電吸収・圧電は 106Hz の極を作るだけの用途では二次的。 C0G をどうしても優先するなら `C52037853` だが、在庫 2,250・メーカー実績不明・個別ページ未取得（検索 API 一覧の値のみ）というリスクを取ることになる。

## 4. `C52923`（ESP32 EN の RC 用、B2）の判定: OK

- 現基板: C_EN_DLY = 100nF (C1525) が ESP_EN -> GND / R_EN_UP = 10kΩ (C25804) が VDD_ESP -> ESP_EN
- 実体: C52923 = CL05A105KA5NQNC / Samsung / C0402 / 1uF 25V X5R +-10% / JLC Basic
- 在庫: LCSC 3,790,400 / SZLCSC 3,663,900、jlcOnSale=1（LCSC 商品ページと EasyEDA API の 2 ソースが一致）
- **判定: OK**

定格 25V は要求の 6.3V 以上を約 4 倍上回る。EN ノードは 3.3V なので DC バイアスによる容量減衰も小さく、10kΩ との時定数は WROOM-32E 推奨の 10kΩ/1µF の意図どおりに出る。フットプリントは現行 C1525 と同じ C0402 で 品番差し替えのみ・銅箔変更なし。

**さらに、部品種類が増えないという利点がある。** C52923 は既に BOM の 10 箇所（C_3V3_IN / C_3V3_M / C_AVDD1_1u / C_LM_IN / C_NLDO_IN / C_PLDO_IN / C_PLDO_OUT / C_VCAP2 / C_VCAP3 / C_VCAP4）で使用中。C_EN_DLY を C52923 にしても品番数が増えず、Basic のままリールも増えない。

- 出典: https://www.lcsc.com/product-detail/C52923.html , https://easyeda.com/api/products/C52923/components

## 追加調査で参照した URL

- `C72044`: https://www.lcsc.com/product-detail/C72044.html , https://jlcpcb.com/partdetail/EverlightElec-19_217_R6C_AL1M2VY3T/C72044 , https://easyeda.com/api/products/C72044/components
- `C72038`: https://jlcpcb.com/partdetail/C72038 , https://easyeda.com/api/products/C72038/components
- `C2286`: https://jlcpcb.com/partdetail/Hubei_KentoElec-KT0603R/C2286 , https://easyeda.com/api/products/C2286/components
- `C183844`: https://easyeda.com/api/products/C183844/components
- `C1017`: https://jlcpcb.com/partdetail/Sunlord-GZ2012D601TF/C1017 , https://easyeda.com/api/products/C1017/components
- `C23967`: https://jlcpcb.com/partdetail/C23967 , https://easyeda.com/api/products/C23967/components
- `C284989`: https://easyeda.com/api/products/C284989/components
- `C281752`: https://easyeda.com/api/products/C281752/components
- `C52037853`: https://easyeda.com/api/eda/product/search?keyword=1.5nF%200402%20C0G&needAggs=false&currPage=1&pageSize=20  (検索一覧)
- `C14442`: https://easyeda.com/api/products/C14442/components
- `C52923`: https://www.lcsc.com/product-detail/C52923.html , https://easyeda.com/api/products/C52923/components

# カート投入時の差替 2026-08-28

JLC のカートに入れた時点で 2 品番が**実装在庫 0（20 shortfall）**となり、その場で差し替えた。正本は
`data/bom_fixes_2026-08-28.json`。**どちらもフットプリント・銅箔・CPL は不変**で、変わったのは
`data/parts_lcsc.csv` と基板の Value/MPN/LCSC フィールド、`fab/BOM_JLCPCB.csv` の当該 2 行だけ。

| designator | 旧 | 新 | 根拠 |
|---|---|---|---|
| `D_LED` | `C72044`（Everlight 赤 Vf1.95V） | **`C84268`** NationStar NCD0603Y1 / 黄 595nm / Vf≈2.0V | EasyEDA パッケージ名が `LED0603-RD` で現フットプリントと完全一致、生データ pin1=K / pin2=A で現基板 pad1=GND（カソード）と一致するため**回転補正なし（CPL 0° のまま）**。(3.3−2.0)/330 ≈ 3.9mA。JLC Extended / 実装在庫 605,820 / Economic 対応。BOM value 'LED_Y'（黄）とも整合。不採用: `C2286`（Basic・在庫最大だが pin1=A で極性反転、CPL 180° 補正が要る）、`C84263`（赤・pin1=K だが Standard 専用） |
| `F1` | `C369159`（JK-NSMD050-13.2V） | **`C43379`** RUILON SMD1206P050TF/13.2 | 1206・hold 500mA / trip 1A / **13.2V** で旧品と定格が同一＝設計変更なし。本体 3.6×1.9mm は現 `F1206` ランド（パッド 1.19×1.728 @ ±1.445mm）に対し長手は余裕、幅は片側 0.086mm はみ出し（PPTC では許容）。**CPL 90° のまま**。JLC Extended / 実装在庫 19,984。6V 品 `C69688` / `C883122` より 13.2V の余裕を優先 |

Extended 品番数は増減なし（`C72044`→`C84268`、`C369159`→`C43379` とも Extended）。
再生成後の照合: Gerber・ドリル 14 ファイルは生成時刻行を除いて**全ファイル一致**、`fab/CPL_JLCPCB.csv` は**完全一致**、
`fab/BOM_JLCPCB.csv` は 30 行中この 2 行のみ差分。S7a 16/16・S8 30/30・ACCEPTANCE A–G 40/40 いずれも pass。

> この節は手書き。`scripts/40_gen_bom_report.py` はこのファイルの生成元だが、ECO-5 で
> `C23967` 等が `data/parts_lcsc.csv` に入って以降 `JUDGE` に定義が無く `KeyError` で止まるため、
> 本レポートは 2026-08-28 時点の凍結スナップショットとして手で追記している（本件以前からの既存事象）。

# 追記 2026-08-28（3）— `U_MCU` を ESP32-WROOM-32E → **32UE** に差し替えた

カート投入後の配置レビューで、**32E の本体（25.5 × 18 mm）が ADS1299 の上に乗っている**ことが
判明した。ACCEPTANCE に基準 **H（部品本体の重なり）** が追加され、`scripts/64_body_overlap.py` が
F.Fab 外形どうしで測った結果は次の 4 件（負値＝食い込み）:

| 組 | 隙間 [mm] |
|---|---|
| `C_AVDD1_10n` × `U_MCU` | −3.1384 |
| `U_ADS` × `U_MCU` | −2.8124 |
| `C_DVDD_P40` × `U_MCU` | −1.6484 |
| `C_AVDD1_100n` × `U_MCU` | −0.8524 |

25.5 mm のうち **6.3 mm は PCB アンテナとその keep-out** で、しかもその端が ADS1299 側（−X）を
向いている。**`ESP32-WROOM-32UE-N4`（`C701344`）はこの 6.3 mm が無いだけの同一製品**で、
Espressif のデータシートが「The pin layout of ESP32-WROOM-32UE is the same as that of
ESP32-WROOM-32E, except that ESP32-WROOM-32UE has no keepout zone」と明記している。

## 何を変えたか — **銅箔は 1 mil も動いていない**

`scripts/37_umcu_32ue.py`（S5_L8）。フットプリントの**図形と文字だけ**を書き換える:

| レイヤ | 変更 |
|---|---|
| F.Fab | 25.5 × 18 の外形 4 本を **19.2 × 18**（ローカル x −9.945…+9.255 / y ±9.000）に引き直し。1 番ピン印の塗り polygon は新しい角へ +6.5825 mm 平行移動 |
| F.SilkS | 10 本（アンテナ keep-out 線 x −10.1925 を含む）→ **7 本**。線幅 0.254 mm も、パッド列を跨ぐ手前で 0.206 mm 空ける流儀も既存の 32E 外形と同じ（座標は**パッドから導出**しているので、偶然ではなく一致する） |
| F.CrtYd | 本体 + 0.25 mm の矩形 |
| フィールド | Value / MPN = `ESP32-WROOM-32UE-N4`、LCSC = **`C701344`** |

**パッド 47 枚（38 + サーマル 9）・ネット・トラック・ビア・ゾーンは 1 つも触っていない。**
`P.counts` は前後で `{footprints 141, tracks 1248, vias 241, npth 6, pth 16}` で不変、
契約パリティ 0、DRC error 0 / unconnected 0 / 新規署名 0。

## 差し替え後の実測

| 相手 | 本体間 [mm] | 本体→相手パッド [mm] |
|---|---|---|
| `U_ADS` | −2.8124 → **+3.7701** | −4.2369 → **+2.3456** |
| `C_AVDD1_10n` | −3.1384 → **+3.4441** | −3.2829 → **+3.2996** |
| `C_DVDD_P40` | −1.6484 → **+4.9341** | −1.6129 → **+4.9696** |
| `C_AVDD1_100n` | −0.8524 → **+5.7301** | −0.9969 → **+5.5856** |
| `R_IO2_DN` / `R_IO15_DN` | 0.5606 → **0.2781** | 0.2592 → **0.0022**（F.Fab 外形中心線まで） |

ACCEPTANCE H は **pass**（残る重なり 3 件はすべて許容リスト: `AMS1117`×`H4` と
`J1`×`PEG1`/`PEG2`＝J1 自身の NPTH ペグ穴）。

## 東側 2 点（`R_IO2_DN` / `R_IO15_DN`）を動かさなかった理由

本体東端が x = 174.213、この 2 点の pad 1 の西端が x = 174.2152 で **0.0022 mm** しかない。
+0.30 mm 東へ逃がす案を `scripts/38_nudge_io_pulldowns.py`（S5_L9）で実測したが**不可**:

- `ESP_RXD` が **x = 175.2195 の F.Cu を y 91.2775→103.165 まで縦断**しており（幅 0.1525 mm）、
  pad 1 の東端 175.0217 との隙間は **0.1216 mm**。0.30 mm 動かすと pad 1 がこのトラックに乗り、
  `ESP_IO2` / `ESP_IO15` が `ESP_RXD` と短絡する
- clearance 0.0889 mm を守れる最大の東移動は **0.030 mm**（必要量 0.198 mm に対して）

**そして 0.0022 mm という数字が隠している事実のほうが重要**: `R_IO2_DN` の pad 1 は
`U_MCU` の pad 24（castellation）と **0.7953 mm 重なって同じランドを共有**しており、
両者は同一ネット `ESP_IO2` である（`R_IO15_DN` pad 1 と pad 23 / `ESP_IO15` も同じ）。
モジュール本体の下に**別部品の独立したはんだ接合は存在しない**。モジュール自身の
castellation も本体端から 0.7975 mm 外へ出ている（そういう部品である）。

なお本体位置 x −9.945…+9.255 は、19.2 mm を置ける 2 通りのうち**東寄り＝悲観側**の解釈である
（32E の外形から keep-out 6.3 mm を引くと −10.2275…+8.9725 になり、この 2 点は 0.2847 mm 空く）。
西側は U_ADS まで 3.4 mm 以上あるのでどちらでも変わらない。

## CPL の回転だけ 0° → **90°**

`C701344` の JLC / EasyEDA フットプリントは**モジュール長辺が Y 軸方向**に描かれており、
repo のフットプリントに対して +90° CCW（38 パッド全部が +90° で一致、原点はどちらも
パッド外接矩形の中心）。したがって **Mid X / Mid Y は不変、Rotation だけ 90**。
基板側は 0° のまま正しいので、`data/cpl_overrides.json` に理由付きで置き、
`scripts/61_make_bom_cpl.py` が pos 出力後に当該行だけ書き換え、`gates/S8.json` に記録する。

## アンテナについて

**32UE にオンボードアンテナは無い**（代わりに U.FL コネクタ。本基板では未接続で使わない）。
Rev.A の通信は USB-UART のみで WiFi/BLE を初期化しないため機能上の欠落はない
（Espressif: RF スタック未初期化なら RF ピンはオープンで可）。
**Rev.B で無線を使うなら外部アンテナが必要**になる。
併せて、旧レポート §7 にあった「アンテナが基板内側を向いている（Rev.A 受容）」は
**部品変更により消滅した**（改善したのではなく、アンテナ自体が無くなった）。

## 再出力した製造データの差分（生成時刻行を除く）

| ファイル | 差分 | 由来 |
|---|---|---|
| `F_Cu` / `B_Cu` / `In1_Cu` / `In2_Cu` / `F_Mask` / `F_Paste` / `PTH.drl` | 変化 | **L7（`R_CC1` の移設）のみ**。変化した座標は全て x 172〜179 / y −116〜−106 の R_CC1 窓の中（内層は追加 via 2 本ぶんのアンチパッド。ベタ面積 GND In1 −1.03 mm² / USB_5V In2 −1.03 mm² ＝ 半径 0.394 mm の穴 2 個ぶん） |
| `F_Silkscreen` | 変化 | R_CC1 の移動（112 点）＋ **U_MCU の外形（30 点）**。それ以外の座標はゼロ |
| `Edge_Cuts` / `B_Mask` / `B_Paste` / `B_Silkscreen` / `NPTH.drl` / `.gbrjob` | **完全一致** | |
| `BOM_JLCPCB.csv` | 30 行中 **1 行**（`U_MCU`: `C701341` → `C701344`、Value / MPN も 32UE へ） | Footprint 欄 `WIFI-SMD_ESP32-WROOM-32E` は 32E/32UE 共通のランドパターン名なので据え置き |
| `CPL_JLCPCB.csv` | 133 行中 **2 行**（`R_CC1` 位置・回転／`U_MCU` 回転 90°） | 他 131 行は完全一致 |

ゲート: DRC error 0 / unconnected 0、契約パリティ 0、アナログ 40 ネット差分 0（`--baseline 2b18a8c`）、
S5_L8 16/16・S5_L9 9/9・S7_body 3/3・ACCEPTANCE A–G 40/40・S8 31/31。

> 既知の未修正（軽微）: `scripts/47_layout_quality.py` の J11「ESP32 antenna clear of the board」は
> 32E 前提の文言（`ok: null` の情報項目）で、32UE ではアンテナ自体が無い。指標は判定に使われて
> いないため、この作業では文言を変更していない。

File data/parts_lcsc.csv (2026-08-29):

designator | value | mpn | lcsc | package | easyeda_footprint | kicad_footprint | eco | source | dnp | fix
AMS1117 | AMS1117-3.3 | AMS1117-3.3 | C6186 | SOT-223 | SOT-223-3_L6.5-W3.4-P2.30-LS7.0-BR |  |  | fab_2026-08-16 BOM
C_3V3_B | 10uF | CL10A106KP8NNNC | C19702 | 0603 | C0603 |  | ECO-2#10 | fab_2026-08-16 BOM
C_3V3_B2 | 10uF | CL10A106KP8NNNC | C19702 | 0603 | C0603 |  | ECO-2#10 | fab_2026-08-16 BOM
C_3V3_H | 100nF | CL05B104KO5NNNC | C1525 | 0402 | C0402 |  |  | fab_2026-08-16 BOM
C_3V3_H2 | 100nF | CL05B104KO5NNNC | C1525 | 0402 | C0402 |  |  | fab_2026-08-16 BOM
C_3V3_IN | 1uF | CL05A105KA5NQNC | C52923 | 0402 | C0402 |  |  | fab_2026-08-16 BOM
C_3V3_M | 1uF | CL05A105KA5NQNC | C52923 | 0402 | C0402 |  |  | fab_2026-08-16 BOM
C_3V3_OUT | 10uF | CL10A106KP8NNNC | C19702 | 0603 | C0603 |  | ECO-2#10 | fab_2026-08-16 BOM
C_AVDD1_100n | 100nF | CL05B104KO5NNNC | C1525 | 0402 | C0402 |  |  | fab_2026-08-16 BOM
C_AVDD1_10n | 10nF 50V X7R 0402 | CL05B103KB5NNNC | C15195 | 0402 | C0402 |  |  | fab_2026-08-16 BOM |  | bom-verify
C_AVDD1_10u | 10uF | CL10A106KP8NNNC | C19702 | 0603 | C0603 |  | ECO-2#10 | fab_2026-08-16 BOM
C_AVDD1_1u | 1uF | CL05A105KA5NQNC | C52923 | 0402 | C0402 |  |  | fab_2026-08-16 BOM
C_AVDD_B | 10uF | CL10A106KP8NNNC | C19702 | 0603 | C0603 |  | ECO-2#10 | fab_2026-08-16 BOM
C_AVDD_H | 100nF | CL05B104KO5NNNC | C1525 | 0402 | C0402 |  |  | fab_2026-08-16 BOM
C_AVDD_P19 | 100nF | CL05B104KO5NNNC | C1525 | 0402 | C0402 |  |  | fab_2026-08-16 BOM
C_AVDD_P3 | 100nF | CL05B104KO5NNNC | C1525 | 0402 | C0402 |  |  | fab_2026-08-16 BOM
C_AVDD_P31 | 100nF | CL05B104KO5NNNC | C1525 | 0402 | C0402 |  |  | fab_2026-08-16 BOM
C_AVDD_P36 | 100nF | CL05B104KO5NNNC | C1525 | 0402 | C0402 |  |  | fab_2026-08-16 BOM
C_AVDD_P59 | 1uF | CL05A105KA5NQNC | C52923 | 0402 | C0402 |  |  | fab_2026-08-16 BOM |  | R29-4
C_AVDD_P64 | 100nF | CL05B104KO5NNNC | C1525 | 0402 | C0402 |  |  | fab_2026-08-16 BOM
C_AVSS_B | 10uF | CL10A106KP8NNNC | C19702 | 0603 | C0603 |  | ECO-2#10 | fab_2026-08-16 BOM
C_AVSS_H | 100nF | CL05B104KO5NNNC | C1525 | 0402 | C0402 |  |  | fab_2026-08-16 BOM
C_AVSS_P17 | 100nF | CL05B104KO5NNNC | C1525 | 0402 | C0402 |  |  | fab_2026-08-16 BOM
C_AVSS_P30 | 100nF | CL05B104KO5NNNC | C1525 | 0402 | C0402 |  |  | fab_2026-08-16 BOM
C_AVSS_P37 | 100nF | CL05B104KO5NNNC | C1525 | 0402 | C0402 |  |  | fab_2026-08-16 BOM
C_AVSS_P60 | 100nF | CL05B104KO5NNNC | C1525 | 0402 | C0402 |  |  | fab_2026-08-16 BOM
C_BIAS_INV | 1.5nF 50V X7R 0402 | CL05B152KB5NNNC | C23967 | 0402 | C0402 |  |  | fab_2026-08-16 BOM |  | ECO-5
C_BULK | 10uF | CL10A106KP8NNNC | C19702 | 0603 | C0603 |  | ECO-2#10 | fab_2026-08-16 BOM
C_CM1N | 1nF 50V C0G 0603 | CL10C102JB8NNNC | C163508 | 0603 | C0603 |  |  | fab_2026-08-16 BOM |  | R29-1
C_CM1P | 1nF 50V C0G 0603 | CL10C102JB8NNNC | C163508 | 0603 | C0603 |  |  | fab_2026-08-16 BOM |  | R29-1
C_CM2N | 1nF 50V C0G 0603 | CL10C102JB8NNNC | C163508 | 0603 | C0603 |  |  | fab_2026-08-16 BOM |  | R29-1
C_CM2P | 1nF 50V C0G 0603 | CL10C102JB8NNNC | C163508 | 0603 | C0603 |  |  | fab_2026-08-16 BOM |  | R29-1
C_CM3N | 1nF 50V C0G 0603 | CL10C102JB8NNNC | C163508 | 0603 | C0603 |  |  | fab_2026-08-16 BOM |  | R29-1
C_CM3P | 1nF 50V C0G 0603 | CL10C102JB8NNNC | C163508 | 0603 | C0603 |  |  | fab_2026-08-16 BOM |  | R29-1
C_CM4N | 1nF 50V C0G 0603 | CL10C102JB8NNNC | C163508 | 0603 | C0603 |  |  | fab_2026-08-16 BOM |  | R29-1
C_CM4P | 1nF 50V C0G 0603 | CL10C102JB8NNNC | C163508 | 0603 | C0603 |  |  | fab_2026-08-16 BOM |  | R29-1
C_CM5N | 1nF 50V C0G 0603 | CL10C102JB8NNNC | C163508 | 0603 | C0603 |  |  | fab_2026-08-16 BOM |  | R29-1
C_CM5P | 1nF 50V C0G 0603 | CL10C102JB8NNNC | C163508 | 0603 | C0603 |  |  | fab_2026-08-16 BOM |  | R29-1
C_CM6N | 1nF 50V C0G 0603 | CL10C102JB8NNNC | C163508 | 0603 | C0603 |  |  | fab_2026-08-16 BOM |  | R29-1
C_CM6P | 1nF 50V C0G 0603 | CL10C102JB8NNNC | C163508 | 0603 | C0603 |  |  | fab_2026-08-16 BOM |  | R29-1
C_CM7N | 1nF 50V C0G 0603 | CL10C102JB8NNNC | C163508 | 0603 | C0603 |  |  | fab_2026-08-16 BOM |  | R29-1
C_CM7P | 1nF 50V C0G 0603 | CL10C102JB8NNNC | C163508 | 0603 | C0603 |  |  | fab_2026-08-16 BOM |  | R29-1
C_CM8N | 1nF 50V C0G 0603 | CL10C102JB8NNNC | C163508 | 0603 | C0603 |  |  | fab_2026-08-16 BOM |  | R29-1
C_CM8P | 1nF 50V C0G 0603 | CL10C102JB8NNNC | C163508 | 0603 | C0603 |  |  | fab_2026-08-16 BOM |  | R29-1
C_DIF1 | 10nF_NP0_50V | 0805N103J500CT | C237168 | 0805 | C0805 |  | ECO-2#6 | fab_2026-08-16 BOM
C_DIF2 | 10nF_NP0_50V | 0805N103J500CT | C237168 | 0805 | C0805 |  | ECO-2#6 | fab_2026-08-16 BOM
C_DIF3 | 10nF_NP0_50V | 0805N103J500CT | C237168 | 0805 | C0805 |  | ECO-2#6 | fab_2026-08-16 BOM
C_DIF4 | 10nF_NP0_50V | 0805N103J500CT | C237168 | 0805 | C0805 |  | ECO-2#6 | fab_2026-08-16 BOM
C_DIF5 | 10nF_NP0_50V | 0805N103J500CT | C237168 | 0805 | C0805 |  | ECO-2#6 | fab_2026-08-16 BOM
C_DIF6 | 10nF_NP0_50V | 0805N103J500CT | C237168 | 0805 | C0805 |  | ECO-2#6 | fab_2026-08-16 BOM
C_DIF7 | 10nF_NP0_50V | 0805N103J500CT | C237168 | 0805 | C0805 |  | ECO-2#6 | fab_2026-08-16 BOM
C_DIF8 | 10nF_NP0_50V | 0805N103J500CT | C237168 | 0805 | C0805 |  | ECO-2#6 | fab_2026-08-16 BOM
C_DVDD_10u | 10uF | CL10A106KP8NNNC | C19702 | 0603 | C0603 |  | ECO-2#10 | fab_2026-08-16 BOM
C_DVDD_B | 10uF | CL10A106KP8NNNC | C19702 | 0603 | C0603 |  | ECO-2#10 | fab_2026-08-16 BOM
C_DVDD_H | 100nF | CL05B104KO5NNNC | C1525 | 0402 | C0402 |  |  | fab_2026-08-16 BOM
C_DVDD_P40 | 100nF | CL05B104KO5NNNC | C1525 | 0402 | C0402 |  |  | fab_2026-08-16 BOM
C_DVDD_P58 | 100nF | CL05B104KO5NNNC | C1525 | 0402 | C0402 |  |  | fab_2026-08-16 BOM
C_EN_DLY | 1uF 0402 | CL05A105KA5NQNC | C52923 | 0402 | C0402 |  |  | fab_2026-08-16 BOM |  | B2
C_HF | 100nF | CL05B104KO5NNNC | C1525 | 0402 | C0402 |  |  | fab_2026-08-16 BOM
C_LM_FLY | 10uF | CL10A106KP8NNNC | C19702 | 0603 | C0603 |  | ECO-2#10 | fab_2026-08-16 BOM
C_LM_IN | 4.7uF 10V X5R 0402 | CL05A475MP5NRNC | C23733 | 0402 | C0402 |  |  | fab_2026-08-16 BOM |  | R29-3
C_LM_OUT | 10uF | CL10A106KP8NNNC | C19702 | 0603 | C0603 |  | ECO-2#10 | fab_2026-08-16 BOM
C_NLDO_IN | 1uF | CL05A105KA5NQNC | C52923 | 0402 | C0402 |  |  | fab_2026-08-16 BOM
C_NLDO_OUT | 4.7uF 10V X5R 0402 | CL05A475MP5NRNC | C23733 | 0402 | C0402 |  | ECO-2#8 | fab_2026-08-16 BOM |  | R29-2
C_NR | 10nF | CL05B103KB5NNNC | C15195 | 0402 | C0402 |  | ECO-2#7 | fab_2026-08-16 BOM
C_PLDO_IN | 1uF | CL05A105KA5NQNC | C52923 | 0402 | C0402 |  |  | fab_2026-08-16 BOM
C_PLDO_OUT | 1uF | CL05A105KA5NQNC | C52923 | 0402 | C0402 |  |  | fab_2026-08-16 BOM
C_RST_DLY | 100nF | CL05B104KO5NNNC | C1525 | 0402 | C0402 |  |  | fab_2026-08-16 BOM
C_USB5V_B | 10uF | CL10A106KP8NNNC | C19702 | 0603 | C0603 |  | ECO-2#10 | fab_2026-08-16 BOM
C_USB5V_H | 100nF | CL05B104KO5NNNC | C1525 | 0402 | C0402 |  |  | fab_2026-08-16 BOM
C_USB_V3 | 100nF | CL05B104KO5NNNC | C1525 | 0402 | C0402 |  |  | fab_2026-08-16 BOM
C_USB_VCC | 100nF | CL05B104KO5NNNC | C1525 | 0402 | C0402 |  |  | fab_2026-08-16 BOM
C_VCAP1 | 100uF | CL31A107MQHNNNE | C15008 | 1206 | C0603 | Capacitor_SMD:C_1206_3216Metric | ECO-3#11 | fab_2026-08-16 BOM |  | R29-5
C_VCAP1_H | 100nF | CL05B104KO5NNNC | C1525 | 0402 |  | ProPrj_The-easyedapro:C0402 | ECO-3#11 | ECO-1 (new part)
C_VCAP2 | 1uF | CL05A105KA5NQNC | C52923 | 0402 |  | ProPrj_The-easyedapro:C0402 | ECO-1#4 | ECO-1 (new part)
C_VCAP3 | 1uF | CL05A105KA5NQNC | C52923 | 0402 |  | ProPrj_The-easyedapro:C0402 | ECO-1#5 | ECO-1 (new part)
C_VCAP3_H | 100nF | CL05B104KO5NNNC | C1525 | 0402 |  | ProPrj_The-easyedapro:C0402 | ECO-1#5 | ECO-1 (new part)
C_VCAP4 | 1uF | CL05A105KA5NQNC | C52923 | 0402 | C0402 |  |  | fab_2026-08-16 BOM
C_VREFP_100n | 100nF | CL05B104KO5NNNC | C1525 | 0402 | C0402 |  |  | fab_2026-08-16 BOM
C_VREFP_10n | 10nF 50V X7R 0402 | CL05B103KB5NNNC | C15195 | 0402 | C0402 |  |  | fab_2026-08-16 BOM |  | bom-verify
C_VREFP_10u | 10uF 50V X5R 1206 | CL31A106KBHNNNE | C13585 | 1206 | C0603 | Capacitor_SMD:C_1206_3216Metric | ECO-3#12 | fab_2026-08-16 BOM |  | bom-verify
D_ESD | USBLC6-2SC6 | USBLC6-2SC6 | C7519 | SOT-23-6 | SOT-23-6_L2.9-W1.6-P0.95-LS2.8-BL |  |  | fab_2026-08-16 BOM
D_LED | LED yellow 0603 Vf1.6-2.6V | NCD0603Y1 | C84268 | 0805 | LED0603-RD |  |  | fab_2026-08-16 BOM |  | bom-verify
F1 | PTC 0.5A hold / 1A trip / 13.2V 1206 | SMD1206P050TF/13.2 | C43379 | 1206 | F1206 |  |  | fab_2026-08-16 BOM |  | bom-verify
FB1 | 600R@100MHz 0805 | GZ2012D601TF | C1017 | 0805 | L0805 |  |  | fab_2026-08-16 BOM |  | bom-verify
FB2 | 600R@100MHz 0805 | GZ2012D601TF | C1017 | 0805 | L0805 |  |  | fab_2026-08-16 BOM |  | bom-verify
FB3 | 600R@100MHz 0805 | GZ2012D601TF | C1017 | 0805 | L0805 |  |  | fab_2026-08-16 BOM |  | bom-verify
FB4 | 600R@100MHz 0805 | GZ2012D601TF | C1017 | 0805 | L0805 |  |  | fab_2026-08-16 BOM |  | bom-verify
FB5 | 600R@100MHz 0805 | GZ2012D601TF | C1017 | 0805 | L0805 |  |  | fab_2026-08-16 BOM |  | bom-verify
J1 | USB-C_16P | TYPE-C 16PIN 2MD(073) | C2765186 | USB-C-SMD | USB-C-SMD_TYPE-C-6PIN-2MD-073 |  |  | fab_2026-08-16 BOM
J2 | Header_2x6 | PZ254V-11-12P | C2840012 | HDR-2.54-2x6 | HDR-TH_12P-P2.54-V-M |  |  | fab_2026-08-16 BOM
LM2664 | LM2664 | LM2664M6X/NOPB | C108573 | SOT-23-6 | SOT-23-6_L2.9-W1.6-P0.95-LS2.8-BR |  |  | fab_2026-08-16 BOM
Q_EN | S8050 | S8050 J3Y(RANGE:200-350) | C2146 | SOT-23-3 | SOT-23-3_L3.0-W1.7-P0.95-LS2.9-BR |  |  | fab_2026-08-16 BOM
Q_IO0 | S8050 | S8050 J3Y(RANGE:200-350) | C2146 | SOT-23-3 | SOT-23-3_L3.0-W1.7-P0.95-LS2.9-BR |  |  | fab_2026-08-16 BOM
R_BIAS_FB | 1M | 0805W8F1004T5E | C17514 | 0805 | R0805 |  |  | fab_2026-08-16 BOM
R_BIAS_SER | 1M | 0805W8F1004T5E | C17514 | 0805 | R0805 |  |  | fab_2026-08-16 BOM
R_CC1 | 5.1k | 0603WAF5101T5E | C23186 | 0603 | R0603 |  |  | fab_2026-08-16 BOM
R_CC2 | 5.1k | 0603WAF5101T5E | C23186 | 0603 | R0603 |  |  | fab_2026-08-16 BOM
R_CS_UP | 10k | 0603WAF1002T5E | C25804 | 0603 | R0603 |  |  | fab_2026-08-16 BOM
R_DRDY_UP | 10k | 0603WAF1002T5E | C25804 | 0603 | R0603 |  |  | fab_2026-08-16 BOM
R_EN_UP | 10k | 0603WAF1002T5E | C25804 | 0603 | R0603 |  |  | fab_2026-08-16 BOM
R_IN1N | 10k | 0402WGF1002TCE | C25744 | 0402 | R0402 |  |  | fab_2026-08-16 BOM
R_IN1P | 10k | 0402WGF1002TCE | C25744 | 0402 | R0402 |  |  | fab_2026-08-16 BOM
R_IN2N | 10k | 0402WGF1002TCE | C25744 | 0402 | R0402 |  |  | fab_2026-08-16 BOM
R_IN2P | 10k | 0402WGF1002TCE | C25744 | 0402 | R0402 |  |  | fab_2026-08-16 BOM
R_IN3N | 10k | 0402WGF1002TCE | C25744 | 0402 | R0402 |  |  | fab_2026-08-16 BOM
R_IN3P | 10k | 0402WGF1002TCE | C25744 | 0402 | R0402 |  |  | fab_2026-08-16 BOM
R_IN4N | 10k | 0402WGF1002TCE | C25744 | 0402 | R0402 |  |  | fab_2026-08-16 BOM
R_IN4P | 10k | 0402WGF1002TCE | C25744 | 0402 | R0402 |  |  | fab_2026-08-16 BOM
R_IN5N | 10k | 0402WGF1002TCE | C25744 | 0402 | R0402 |  |  | fab_2026-08-16 BOM
R_IN5P | 10k | 0402WGF1002TCE | C25744 | 0402 | R0402 |  |  | fab_2026-08-16 BOM
R_IN6N | 10k | 0402WGF1002TCE | C25744 | 0402 | R0402 |  |  | fab_2026-08-16 BOM
R_IN6P | 10k | 0402WGF1002TCE | C25744 | 0402 | R0402 |  |  | fab_2026-08-16 BOM
R_IN7N | 10k | 0402WGF1002TCE | C25744 | 0402 | R0402 |  |  | fab_2026-08-16 BOM
R_IN7P | 10k | 0402WGF1002TCE | C25744 | 0402 | R0402 |  |  | fab_2026-08-16 BOM
R_IN8N | 10k | 0402WGF1002TCE | C25744 | 0402 | R0402 |  |  | fab_2026-08-16 BOM
R_IN8P | 10k | 0402WGF1002TCE | C25744 | 0402 | R0402 |  |  | fab_2026-08-16 BOM
R_IO0_UP | 10k | 0603WAF1002T5E | C25804 | 0603 | R0603 |  |  | fab_2026-08-16 BOM
R_IO15_DN | 10k | 0603WAF1002T5E | C25804 | 0603 | R0603 |  |  | fab_2026-08-16 BOM | 1 | B4
R_IO2_DN | 10k | 0603WAF1002T5E | C25804 | 0603 | R0603 |  |  | fab_2026-08-16 BOM
R_LED | 330R | 0603WAF3300T5E | C23138 | 0603 | R0603 |  | ECO-2#9 | fab_2026-08-16 BOM |  | B3
R_MISO | 0R | 0805W8F0000T5E | C17477 | 0805 | R0805 |  |  | fab_2026-08-16 BOM
R_MOSI | 0R | 0805W8F0000T5E | C17477 | 0805 | R0805 |  |  | fab_2026-08-16 BOM
R_PWDN_UP | 10k | 0603WAF1002T5E | C25804 | 0603 | R0603 |  |  | fab_2026-08-16 BOM
R_Q_EN_B | 470k | 0603WAF4703T5E | C23178 | 0603 | R0603 |  |  | fab_2026-08-16 BOM |  | R29-6
R_Q_IO0_B | 470k | 0603WAF4703T5E | C23178 | 0603 | R0603 |  |  | fab_2026-08-16 BOM |  | R29-6
R_RST_UP | 10k | 0603WAF1002T5E | C25804 | 0603 | R0603 |  |  | fab_2026-08-16 BOM | 1 | B1
R_SCLK | 0R | 0805W8F0000T5E | C17477 | 0805 | R0805 |  |  | fab_2026-08-16 BOM
R_SRB_SER | 0R | 0805W8F0000T5E | C17477 | 0805 | R0805 |  |  | fab_2026-08-16 BOM
R_START_DN | 10k | 0603WAF1002T5E | C25804 | 0603 | R0603 |  |  | fab_2026-08-16 BOM
TLV70025 | TLV70025 | TLV70025DDCR | C19619 | SOT-353 | SOT-23-5_L3.0-W1.7-P0.95-LS2.8-BR |  |  | fab_2026-08-16 BOM
TPS72325 | TPS72325 | TPS72325DBVR | C69932 | SOT-23-5 | SOT-23-5_L3.0-W1.7-P0.95-LS2.8-BR |  |  | fab_2026-08-16 BOM
U_ADS | ADS1299 | ADS1299IPAGR | C476817 | TQFP-64 | TQFP-64_L10.0-W10.0-P0.50-LS12.0-TL |  |  | fab_2026-08-16 BOM
U_MCU | ESP32-WROOM-32UE-N4 | ESP32-WROOM-32UE-N4 | C701344 | MODULE | WIFI-SMD_ESP32-WROOM-32E |  |  | fab_2026-08-16 BOM |  | bom-verify
U_USB | CH340C | CH340C | C84681 | SOP-16 | SOP-16_L10.0-W3.9-P1.27-LS6.0-BL |  |  | fab_2026-08-16 BOM

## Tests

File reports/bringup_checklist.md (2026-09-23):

# Brain Canvas Rev.A 火入れ手順書（合格値つき）

- 対象: Brain Canvas Rev.A（ADS1299 + ESP32-WROOM-32UE-N4（L8 で 32E から差替、基板上アンテナ無し）+ CH340C、USB-C 5V 給電、61.8×45 mm 4層）
- 前提: `reports/bringup_design_review.md` の **B1／B2／B3 を BOM に反映済み**であること
- 原則: **各ステップの合格値を満たすまで次へ進まない。** 不合格なら末尾「切り分けフロー」へ
- 記録: 各ステップの実測値をこの表に書き込んで残す（Rev.B の判断材料になる）

---

## Step 0. 着手前の確認（机上）

| # | 確認項目 | 合格条件 |
|---|---|---|
| 0-1 | **R_RST_UP が DNP（不実装）** になっているか | 発注 BOM に R_RST_UP の行が無い／DNP 指定。**最重要。実装されていると起動しない個体が出る（GPIO12 ストラップ）** |
| 0-2 | **C_EN_DLY = 1 µF**（C52923）に差し替え済みか | Espressif 推奨 R=10 kΩ / C=1 µF |
| 0-3 | **R_LED = 330 Ω のまま**（差し替えない）／LED は `C84268`（NationStar NCD0603Y1、**黄** Vf≈2.0 V） | (3.3−2.0)/330 ≈ **3.9 mA**。100 Ω 案は「緑 LED (Vf 3.3 V)」を前提とした旧レビューの記述で、**黄 LED では過電流になるので採らない**（`data/bom_fixes_2026-08-28.json` B3 / D_LED） |
| 0-4 | （初号機のみ）**R_IO15_DN を DNP** にしたか | ROM ブートログを見られるようにするため。2 台目以降は実装で可 |
| 0-5 | ECO-1/2/3 と L1〜L6 のレイアウト修理がすべて反映され、最終 DRC が通っているか | 別途 gates の記録を参照 |
| 0-6 | 2026-08-29 の BOM 改訂 4 件が発注 BOM に入っているか | `C_CM1P〜C_CM8N` = **C163508**（1 nF 50 V **C0G** 0603）/ `C_NLDO_OUT`・`C_LM_IN` = **C23733**（4.7 µF 10 V X5R 0402）/ `C_AVDD_P59` = **C52923**（1 µF 0402）。銅箔・CPL は不変（`reports/functional_review_2026-08-29.md`） |

### 必要な器材
- **電流制限つき DC 電源**（0–6 V / 0–500 mA）＋ USB-C ブレークアウト、または USB 電流計つきケーブル
- テスタ（DC 電圧、4 桁半以上）
- オシロスコープ（20 MHz 以上、AC 結合、×10 プローブ）
- PC（`esptool` インストール済み）、USB-C ケーブル（**データ線つき**。充電専用ケーブル不可）
- 短いジャンパ線（J2 の電極短絡用）

---

## Step 1. 無通電チェック（目視＋テスタ）

**通電前に必ず実施する。** 短絡したまま通電すると LM2664 / LDO を壊す。

| # | 測定 | 合格値 |
|---|---|---|
| 1-1 | 目視: 部品の向き（U_ADS pin1 マーク、U_MCU、AMS1117、LDO 3 個、D_ESD、LM2664） | シルクの 1 番表示と一致 |
| 1-2 | 目視: J1(USB-C) のはんだブリッジ、U_ADS(0.5 mm ピッチ) のブリッジ | ブリッジなし |
| 1-3 | USB_5V ↔ GND 抵抗 | **> 1 kΩ**（数十 kΩ〜∞ が正常。数 Ω なら短絡） |
| 1-4 | VDD_ESP ↔ GND 抵抗 | **> 1 kΩ** |
| 1-5 | AVDD ↔ GND 抵抗 | **> 1 kΩ** |
| 1-6 | AVSS ↔ GND 抵抗 | **> 1 kΩ** |
| 1-7 | VNEG5 ↔ GND 抵抗 | **> 1 kΩ** |
| 1-8 | AVDD ↔ AVSS 抵抗 | **> 1 kΩ** |
| 1-9 | CHASSIS_GND ↔ GND | **∞（導通しないのが正常）**。本設計は意図的に非接続（レビュー N4 参照） |

---

## Step 2. 初回通電（電流制限つき電源）

**まだ USB データ線はつながない**（電源のみ）。電流制限を **250 mA** に設定。

| # | 測定 | 合格値 | 実測 |
|---|---|---|---|
| 2-1 | 5.00 V 印加直後の突入電流 | 一瞬 200 mA 前後まで振れてよい（バルク 10 µF×複数の充電） | |
| 2-2 | **定常電流**（10 秒後） | **80–160 mA**（設計値 typ 約 105 mA） | |
| 2-3 | 電源が電流制限に張り付く | **不合格 → 直ちに切る。** 短絡箇所を探す | |
| 2-4 | 部品の発熱（指で触れる） | 熱いものが無いこと。AMS1117 は温かい程度（(5−3.3)×0.07 W ≈ 0.12 W）が正常 | |

> 定常電流が **50 mA 未満**なら ESP32 が起動していない可能性が高い。**60 mA 未満でも次の Step 3 は実施する**（電源系だけ先に確定させる）。

---

## Step 3. レール電圧測定

すべて **GND 基準**で測る。VCAP1 と VREFP だけは AVSS 基準（後述、Step 7）。

| # | ネット | 測定点の目安 | 合格値（GND 基準） | 実測 |
|---|---|---|---|---|
| 3-1 | USB_5V | C_BULK / C_HF の＋側 | **+4.75 〜 +5.25 V** | |
| 3-2 | V5_LM_IN | FB1 の LM2664 側 / C_LM_IN | USB_5V との差 **< 50 mV** | |
| 3-3 | **VNEG5** | LM2664 pin2 / C_LM_OUT | **−4.55 〜 −5.05 V**（無負荷 −5 V、ROUT 12–25 Ω × 約 9 mA で 0.1–0.23 V 降下） | |
| 3-4 | V_NLDO_IN | FB4 の TPS72325 側 / C_NLDO_IN | VNEG5 との差 **< 50 mV** | |
| 3-5 | **AVSS** | TPS72325 pin5 / C_AVSS_H | **−2.45 〜 −2.55 V**（狙い −2.500 V） | |
| 3-6 | V_PLDO_IN | FB2 の TLV70025 側 | USB_5V との差 **< 50 mV** | |
| 3-7 | **AVDD** | TLV70025 pin5 / C_AVDD_H | **+2.45 〜 +2.55 V**（狙い +2.500 V） | |
| 3-8 | V_3V3_IN | FB3 の AMS1117 側 | USB_5V との差 **< 50 mV** | |
| 3-9 | **VDD_ESP** | AMS1117 pin2 / C_3V3_OUT | **+3.20 〜 +3.40 V**。**+3.00 V 未満は不可**（WROOM-32E の VDD33 min = 3.0 V） | |
| 3-10 | **DVDD** | FB5 の ADS1299 側 / C_DVDD_H | VDD_ESP との差 **< 20 mV** | |
| 3-11 | AVDD − AVSS | 差動で測る | **+4.90 〜 +5.10 V**（ADS1299 Abs Max 5.5 V を超えないこと） | |
| 3-12 | AVSS − GND | = 3-5 | **> −3.0 V**（ADS1299 Abs Max: AVSS to DGND ≥ −3 V） | |

> **VNEG5 が 0 V に近い** → LM2664 の SD（pin4）が V+ に来ているか、フライングキャップ C_LM_FLY の実装を確認。
> **AVSS が 0 V** → TPS72325 の EN（pin3）が V_NLDO_IN につながっているか確認（ECO-1#1。EN=GND だと −0.4〜+0.4 V の disable 窓に入り出力が出ない）。

---

## Step 4. リップル・発振の確認（オシロ、AC 結合、プローブのグランドは最短に）

| # | 測定点 | 合格値 | 実測 |
|---|---|---|---|
| 4-1 | USB_5V | **< 50 mVpp** | |
| 4-2 | VNEG5 | **< 30 mVpp**（LM2664 のスイッチングは fSW 40–80 kHz。10 µF フライング/出力なら数 mVpp オーダー） | |
| 4-3 | **AVSS** | **< 5 mVpp、かつ持続発振なし**（レビュー N2: C_NLDO_OUT の実効容量が下限付近。数百 kHz の正弦波状リンギングが見えたら発振） | |
| 4-4 | **AVDD** | **< 5 mVpp、発振なし** | |
| 4-5 | **VDD_ESP** | **< 50 mVpp、発振なし**（レビュー N3: AMS1117 のセラミック出力のみ構成。数百 kHz〜MHz の発振が出たら要対処） | |
| 4-6 | DVDD | < 50 mVpp | |

> 4-3 が発振 → C_NLDO_OUT を 4.7 µF（0402）へ変更、または AVSS 直近に 10 µF を手付け。
> 4-5 が発振 → C_3V3_OUT に 0.5–1 Ω を直列に手付け（ESR 付加）して再確認。

---

## Step 5. ESP32 の起動確認（ROM ブートログ）

USB-C を **PC に接続**（データ線つきケーブル）。シリアルポートを **115200 baud** で開く。

> ROM ブートローダのログは 115200 baud で出る（アプリの `Serial.begin(9600)` とは別）。
> R_IO15_DN を実装したまま（Step 0-4 未実施）だとこのログは**出ない**ので、その場合は 5-3 だけ確認して Step 6 へ進む。

| # | 確認 | 合格 | 不合格の意味 |
|---|---|---|---|
| 5-1 | `rst:0x1 (POWERON_RESET),boot:0x13 (SPI_FAST_FLASH_BOOT)` 相当が出る | **合格** | — |
| 5-2 | `flash read err`／`ets_main.c` でループ／文字化けの連続 | — | **GPIO12 ストラップ（B1）を疑う。** R_RST_UP が実装されていないか目視確認。実装されていたら除去（0603 なので手はんだで外せる）。外せない場合は Step 6-0 の eFuse 手順へ |
| 5-3 | PC 側にシリアルポートが列挙される（`ls /dev/cu.usbserial*` など） | **合格**（CH340C が enumerate している） | ポートが出ない → CH340C の VCC/V3/UD±、USB-C の VBUS/D± 経路（ECO L4 のペグ穴修理）を疑う |
| 5-4 | Step 2 の定常電流が **80 mA 以上**に増える | 合格（ESP32 が動作している） | — |
| 5-5 | **ESP32 の U0RXD（IO3）のアイドル電圧をテスタで測る**（CH340C の TXD が繋がる側。UART が無通信のときの直流電圧） | **3.6〜3.9 V 程度に収まっていれば想定内**（下記） | **5.0 V に張り付く／4 V を大きく超える → その基板は長時間運用に回さない。** Rev.B まで評価用に留める |

> **なぜ 5-5 を測るのか（Rev.A の受容済みリスク）**: 本基板の CH340C は VCC = **5 V** で動いており、
> その TXD / DTR#・RTS# は **5 V ロジック**で ESP32 の U0RXD / EN / IO0 を叩く。
> ESP32 の絶対最大定格は 3.6 V なので、原理的には超過している。実際にはピンの ESD クランプ
> ダイオードが VDD_ESP + 0.3 V あたりに落とすので **3.6〜3.9 V 程度**に収まり、
> 自動リセット用トランジスタ（Q_EN / Q_IO0）の B-C 接合を通る漏れも **55〜100 µA** 程度で、
> ESP32 開発ボードで広く使われている構成でもある。**Rev.A はこれを受容する。**
> 1 枚だけ試すなら**ボッジ**として `U_USB`(CH340C) の **pin16(VCC) を持ち上げて VDD_ESP に繋ぎ、
> pin4(V3) を VCC に短絡**すれば CH340C ごと 3.3 V で動く。
> **Rev.B では CH340C を 3.3 V 駆動にする**（VCC=3.3 V・V3 を VCC に接続）。

### Step 6-0（不合格 5-2 の救済のみ）eFuse による恒久回避
> **不可逆操作。R_RST_UP を物理的に外せる場合は外す方が良い。**
```
espefuse.py --port <PORT> set-flash-voltage 3.3V
```
XPD_SDIO_FORCE + XPD_SDIO_REG + XPD_SDIO_TIEH を焼き、以後 GPIO12(MTDI) は無視される。
書き込みモードに入れるため、実行時は GPIO0 を Low にする必要がある（自動リセット回路が効くので通常は不要）。

---

## Step 6. ファーム書き込み

```
esptool.py --chip esp32 --port <PORT> --baud 460800 flash_id
esptool.py --chip esp32 --port <PORT> --baud 460800 write_flash 0x1000 <bootloader.bin> 0x8000 <partitions.bin> 0x10000 <app.bin>
```
Arduino IDE を使う場合は Board = "ESP32 WROOM DA Module"（Cerelog 準拠）。

| # | 確認 | 合格値 |
|---|---|---|
| 6-1 | `flash_id` が成功し、`Detected flash size: 4MB` 相当が出る | **合格**（自動リセット回路 Q_EN/Q_IO0 が正しく動作している証拠） |
| 6-2 | 手で BOOT ボタンを押す必要がある | 本基板にボタンは無い。自動リセットが効かないなら Q_EN/Q_IO0/R_Q_EN_B/R_Q_IO0_B の実装と向きを確認 |
| 6-3 | 書き込み完了後 `Hard resetting via RTS pin...` で再起動 | 合格 |

### 書き込むファームに入れておくべき変更（レビュー F1/F2/F3）
| 項目 | 内容 |
|---|---|
| **F1** | `MISC1 = 0x00`（**0x20 は不可**）。**ECG は ch3 ではなく ch4**（IN4P=ECGP / IN4N=ECGN）。EEG 使用 ch は `CHnSET = 0x68`（Gain24 + SRB2）、**未使用 ch は `CHnSET = 0x81`**（power-down + MUX short） |
| **F2** | PWDN#/RESET# を High にして待機したあと、**改めて RESET# を Low(≥1 µs)→High**（または RESET コマンド 0x06）→ 18 tCLK(≈9 µs) 待ち → SDATAC → 以降のレジスタ操作 |
| **F3** | **ADS1299 の GPIO レジスタ (0x14) を絶対に書かない**（GPIO1–4 は GND 直結のため、出力 High にすると恒常短絡） |

---

## Step 7. ADS1299 の生存確認

### 7-1. ID レジスタ読み出し（最重要）
`SDATAC`(0x11) を送ってから `RREG 0x00`（0x20, 0x00）を実行。

| 確認 | 合格値 |
|---|---|
| ID レジスタ | **`(ID & 0x1F) == 0x1E`**（典型値 **0x3E**）。上位 3 bit は REV_ID で個体差あり |
| 内訳（SBAS499C Table 12） | bit4 = 1 固定 / DEV_ID[3:2] = 11b（ADS1299-x）/ NU_CH[1:0] = 10b（8ch） |
| 0x00 または 0xFF が返る | **不合格** → 末尾の切り分けフローへ |

### 7-2. 全レジスタのライト／リードバック
CONFIG1 に 0x96、CONFIG3 に 0xEC を書き、読み戻して一致すること。**不一致なら SPI 配線（SCLK/DIN/DOUT/CS#）を疑う。**

### 7-3. VCAP1 の立ち上がり時間（**C_VCAP1 を 100 µF にした影響の実測。必ず実施**）
オシロの **プローブ GND を AVSS に当て**、C_VCAP1 の非 AVSS 側（= ADS1299 pin28）を観測。USB を挿した瞬間からトリガ。

| 確認 | 合格値 |
|---|---|
| VCAP1 が **AVSS 基準で +1.1 V** に達するまでの時間 | ファームの「PWDN/RESET High → 最初の SPI アクセス」までの待機時間より **短い**こと |
| 実測が待機時間（現行 1000 ms）を超える | **待機時間をその 1.5 倍以上に延長する**（SBAS499C §11.1「Issue the reset after tPOR **or after the VCAP1 voltage is greater than 1.1 V, whichever time is longer**」／Figure 67） |
| 参考: tPOR | 2^18 / 2.048 MHz = **128 ms**（内部発振使用時） |
| **VCAP1 の DC 電位（定常、AVSS 基準）を記録** | 期待値 **約 1.2 V**。**1.1 V を割っていたら RESET の条件（§11.1）を満たさないので要調査** |

**VCAP1 の誘電体（X5R）の実測確認**（lead 裁定 2026-09-23: C15008 / CL31A107MQHNNNE の X5R 100 µF のまま。
SBAS499C §11 は「多くの場合 VCAP1 も MLCC」としていて、X5R を避けるのは振動のある系に限った推奨。
ADS1299EVM と OpenBCI Cyton も X5R 100 µF を使っている。1.2 V での実効容量は約 90 µF、最悪でも 72 µF で、帯域は約 0.2 Hz。DS の要求は 10 Hz 未満）。

| 確認 | 方法 | 判断 |
|---|---|---|
| 入力短絡ノイズ・静置 | 全チャネル **MUX=001（入力短絡）**、机上に静置して数十秒記録 | 基準値として記録 |
| 入力短絡ノイズ・装着して動く | 同じ設定で、装着して頭を動かす | 静置と比べる |
| 入力短絡ノイズ・基板を叩く | 同じ設定で、基板を指やペン先で軽く叩く | 静置と比べる |
| 判定 | 叩いたときや動いたときにだけ出るステップ状・リンギング状のノイズ（圧電ノイズ）が見えるか | 出たら **Rev.B で C_VCAP1 をタンタル（A ケース）にすることを検討**し、記録を残す |

### 7-4. VREFP の確認（**初期化後にのみ有効**）
CONFIG3 の PD_REFBUF=1（=0xEC 書き込み）後に測る。

| 測定 | 合格値 |
|---|---|
| **AVSS 基準**の VREFP（pin24） | **+4.49 〜 +4.51 V** |
| **GND 基準**の VREFP | **+1.99 〜 +2.01 V** ← AVSS(−2.5 V) + 4.5 V |

> ⚠️ `08_simplified_power_design.md` の TP 表は「TP_VREFP = +4.500 V」とだけ書いているが、**GND 基準では +2.0 V** である。テスタを GND 基準で当てて「4.5 V が出ない」と誤判定しないこと。

### 7-5. DRDY の確認
`START` を High にして `RDATAC`。GPIO27(DRDY#) をオシロで観測。

| 確認 | 合格値 |
|---|---|
| DRDY# の周期 | **4.00 ms ± 2.5 %**（250 SPS。内部発振の確度 −40〜85 °C で ±2.5 %、25 °C なら ±0.5 %） |
| DRDY# が出ない | CLKSEL(pin52)=DVDD の導通、START(pin38) のレベル、RESET シーケンス（F2）を疑う |

---

## Step 8. ノイズ測定

### 8-1. 内部短絡（デバイス自身のノイズ）
全 ch を `CHnSET = 0x61`（Gain=24, MUX=001 = input shorted to (VREFP+VREFN)/2）に設定、250 SPS、1000 サンプル以上取得。

| 確認 | 合格値 |
|---|---|
| 入力換算ノイズ | **≤ 0.30 µVrms**（SBAS499C **Table 4**: Gain=24 / 250 SPS / −3dB BW 65 Hz の typ は **0.14 µVrms、0.98 µVpp**）。0.14 に近いほど良い |
| 0.5 µVrms を超える | 電源ノイズ（Step 4）またはレイアウトを疑う |

### 8-2. 外部短絡（基板の入力段込み）
J2 の全電極ピンと A2（pin10）をジャンパで短絡し、`CHnSET = 0x60`（Gain=24, MUX=000 normal）で測定。

| 確認 | 合格値 |
|---|---|
| 入力換算ノイズ | **≤ 0.40 µVrms**。理論値は デバイス 0.14 µVrms と直列 20 kΩ の熱雑音 0.146 µVrms(65 Hz 帯域) の二乗和 ≈ **0.20 µVrms** |
| 8-1 と大差ない | 合格（入力段が健全） |
| 8-2 だけ極端に悪い | 入力の 10 kΩ / C_DIF / C_CM の実装、電極ラインのリーク、BIAS ループの発振（8-3）を疑う |

### 8-3. BIAS(DRL) ループの発振確認（**レビュー N1。必ず実施**）
CONFIG3 = 0xEC（PD_BIAS=1）、BIAS_SENSP = 使用 ch のビット を設定した状態で、
オシロで **BIASOUT（R_BIAS_SER の ADS1299 側）** を観測。

| 確認 | 合格値 |
|---|---|
| BIASOUT の波形 | **持続発振が無いこと**（DC ≈ 0 V 付近で静か） |
| 発振している／全 ch のノイズが 8-1 より 1 桁悪い | **C_BIAS_INV を外す（DNP）** → 再測定。改善しなければ **R_BIAS_FB(0805) の上に 1.5 nF(0402) を手付けで並列**に載せる（TI SBAS499C Figure 68 の推奨構成 = 1 MΩ ∥ 1.5 nF に一致させる） |

### 8-4. 電源スイッチングの漏れ込み
8-2 の状態で取得したデータを FFT。

| 確認 | 合格値 |
|---|---|
| 10–65 Hz 帯にスプリアス | 電源起因のスパイクが無いこと（LM2664 の fSW は 40–80 kHz で帯域外だが、折り返しが無いか確認） |
| 50 Hz（マレーシアの商用周波数） | 電極開放時は大きく出て正常。短絡時に大きいなら基板起因 |

### 8-5. 電源ピンのバイパス経路（**afe-adc J1 の裁定の裏づけ。2026-09-24 追加**）
**背景**: J1 は緑だが、DVDD 48/50 の最寄りコンデンサ（C_DVDD_P40）までは F.Cu で 10.6〜13.7 mm あり、経路の L は 3〜14 nH と見積もった。AVDD 19/56/59 は In2 の AVDD ベタ経由（via 2 本）。机上では「ADC 自身の電流は fCLK 同期なので DC に畳まれる」「fMOD = 1.024 MHz では 100 nF のリアクタンス 1.55 Ω に対して経路は 0.02〜0.09 Ω」から、実害なしと判断した。ここではそれを実測で確かめる。

| # | 測定 | 合格値・判定 |
|---|---|---|
| 8-5a | **8-1 の内部短絡ノイズを 10 秒 × 3 回**（全 ch、250 SPS、gain 24、`CHnSET = 0x61`） | **3 回とも 8-1 の合格値（≤ 0.30 µVrms）**。比較の基準は SBAS499C の入力換算ノイズ表（Gain 24 / 250 SPS は typ 0.14 µVrms・0.98 µVpp、§7.5 は MAX 1.35 µVpp / 1 s） |
| 8-5b | **k·fMOD の折り返しトーン**: 8-5a のデータと、同じ設定で DR を最高（16 kSPS）にしたデータを FFT する | **DC と 50 Hz 系以外のスプリアスが、帯域内でノイズ床 +10 dB を超えない**（目安、推測）。スプリアスがあれば、その周波数 f_s から f_s = \|f_src − k·1.024 MHz\| を満たす f_src を探す（LM2664 の fSW 40–80 kHz 系、ESP32 の WiFi/クロック、USB）。根拠は SBAS499C p.24 *"fMOD = fCLK / 2"*、§9.3.2.1.1 *"pass band repeats itself at every fMOD"*、§11 p.70 *"noise that is nonsynchronous with the ADS1299-x operation must be eliminated"* |
| 8-5c | **DVDD のスパイク**: U_ADS pin 50 を、スプリング GND で pin 49（GND）に当てたプローブで見る。帯域 ≥ 200 MHz、SPI 読み出し中に SCLK の立ち上がりでトリガ | **記録する。机上の推定は 50〜100 mVpk（推測）**。**300 mVpk を超えるか、DVDD が 3.0 V を割るなら**、Rev.B の「全電源ピンについて via 0・2 mm 以内に 100 nF を 1 個」を前倒しで検討する（lead に上げる） |

---

## Step 9. 動作確認

| # | 確認 | 合格値 |
|---|---|---|
| 9-1 | ステータス LED（GPIO17）が点灯する | 目視で点灯（**R_LED = 330 Ω・黄 LED C84268 で約 3.9 mA**）。暗すぎて視認できないなら Rev.B で 220 Ω 前後を検討する（3.3 V GPIO のソース電流上限に注意） |
| 9-2 | 37 バイトパケットがホストに届く | START marker `0xAB 0xCD` / LENGTH `0x1F` / END `0xDC 0xBA`、チェックサム一致 |
| 9-3 | ハンドシェイクで 115200 baud に切り替わる | パケットの取りこぼしが無い |
| 9-4 | ch4 に ECG 電極を当てて心電波形が見える | R 波が識別できる（F1 の ch4 設定が正しいことの確認） |
| 9-5 | ch1/ch2 に前頭電極＋A2 参照で EEG が見える | 開閉眼でアルファ波（8–12 Hz）の増減が見える |
| 9-6 | 実運用電源での連続動作（30 分） | **モバイルバッテリでは自動オフしないことを確認する**（消費約 105 mA。低電流オートオフ付きのバッテリだと切れる。切れる個体なら PC の USB ポートか低電流モード対応バッテリを使う運用に決める） |

---

## 切り分けフロー

### A. Step 2 で電流制限に張り付く
1. 電源を切り、Step 1 の抵抗測定をやり直す
2. 5 V を 1 V まで下げて印加し、サーモカメラ／指で発熱箇所を探す
3. FB1/FB2/FB3 を順に外して、どの系統が短絡しているか切り分ける

### B. Step 3 で VNEG5 が出ない
- LM2664 pin4(SD) が pin5(V+) と同電位か → 違えば実装不良
- C_LM_FLY(10 µF) が pin6(CAP+)–pin3(CAP−) に載っているか
- pin2(OUT) の負荷が重すぎないか（VNEG5–GND 抵抗を測る）

### C. Step 3 で AVSS が出ない（VNEG5 は出ている）
- **TPS72325 pin3(EN) が pin2(IN) と同電位（≈−4.8 V）か**を最優先で確認
  - EN が 0 V なら disable 窓（−0.4〜+0.4 V）に入っており出力は出ない（ECO-1#1 未反映）
- pin1=GND / pin5=OUT の向き（DBV: 1 GND, 2 IN, 3 EN, 4 NR, 5 OUT）

### D. Step 5 で ESP32 が起動しない
1. VDD_ESP が **3.0 V 以上**か（Step 3-9）
2. ESP_EN の電圧が VDD_ESP と同じか（R_EN_UP 実装確認）。電源投入からの立ち上がりをオシロで見て、**τ ≈ 10 ms** で 3.3 V に達しているか
3. **`flash read err` が出る → GPIO12。R_RST_UP を外す（最優先）**
4. ROM ログが全く出ない → R_IO15_DN が実装されている（仕様どおり）か、CH340C 側の問題
5. CH340C が列挙されない → USB-C の VBUS/D± 経路（ECO L4 のペグ穴修理が正しく入っているか）、CH340C の V3(pin4) に 100 nF があるか

### E. Step 7-1 で ID が 0x00 / 0xFF
| 症状 | 疑うところ |
|---|---|
| 常に 0x00 | DOUT が Low 固定。ADS1299 が動いていない（AVDD/AVSS/DVDD を再確認）、または R_MISO(0 Ω) 未実装 |
| 常に 0xFF | DOUT が High 固定／未接続。R_MISO、ADS pin43 のはんだ、CS# が Low になっているか |
| 値が不安定 | SPI モード（**SPI_MODE1 = CPOL0/CPHA1**）、クロック 4 MHz、CS# のタイミング |
| SCLK が出ていない | ESP32 の VSPI 設定（GPIO18/23/19/5）とファームの define |
| DRDY が来ない | CLKSEL(pin52)=DVDD、RESET シーケンス（F2）、START(pin38) |

### F. Step 8 でノイズが規格の 3 倍以上
1. Step 4 の電源リップル／発振を再確認
2. 8-3 の BIAS ループ発振を確認（C_BIAS_INV を外して再測定）
3. USB ケーブルを外し、モバイルバッテリ単独給電で再測定（PC 経由のグランドループ切り分け）
4. 筐体・電極ケーブルのシールド（**J2 pin12 は CHASSIS_GND = USB シェル直結。電極を接続しないこと**）

---

## 記録テンプレート

```
基板シリアル:            測定日:            測定者:
Step 2 定常電流:        mA
Step 3  USB_5V:      V   VNEG5:      V   AVSS:      V   AVDD:      V   VDD_ESP:      V   DVDD:      V
Step 4  AVSS ripple:    mVpp   AVDD:    mVpp   VDD_ESP:    mVpp   発振の有無:
Step 5  ROM ログ: 出た / 出ない / flash read err     CH340 列挙: OK / NG
Step 6  write_flash: OK / NG
Step 7  ID = 0x        VCAP1 が +1.1V(AVSS基準) に達する時間:      ms
        VREFP(AVSS基準):      V     DRDY 周期:      ms
Step 8  内部短絡ノイズ:      µVrms   外部短絡:      µVrms   BIAS 発振: 無 / 有
Step 9  LED: OK/NG   パケット: OK/NG   ECG(ch4): OK/NG   EEG α波: OK/NG   バッテリ 30 分: OK/NG
所見:
```

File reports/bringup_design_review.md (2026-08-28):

# Brain Canvas Rev.A 火入れ前 設計レビュー（データシート実読）

- 日付: 2026-08-28
- 回路の正: `contract/netlist_easyeda_api_2026-08-28.tsv`（423 行）
- BOM の正: `data/parts_lcsc.csv`
- 基板: `board/Therapia_EEG-HRV.kicad_pcb`（HEAD スナップショットを読み取りのみ）
- 方針: **推測ではなく一次資料（メーカー PDF）を実読して判定**。推測箇所は「推測」と明記した。

## 0. 判定サマリ

| 分類 | 件数 | 項目 |
|---|---|---|
| **要対処（発注前・BOM のみ）** | 3 | B1 GPIO12 ストラップ / B2 EN の RC / B3 LED 電流 |
| **要対処（ファーム・手順）** | 4 | F1 MISC1=0x00 / F2 ADS RESET の再パルス / F3 ADS GPIO レジスタ禁止 / F4 eFuse 予備手順 |
| **要対処（発注フロー）** | 1 | J1 JLC PCBA サービス選択（基板サイズ最小値） |
| **注意（Rev.A 受容・実測で判断）** | 5 | N1 BIASINV 補償 / N2 C_NLDO_OUT 実効容量 / N3 AMS1117 セラミック出力 / N4 CHASSIS_GND 浮き / N5 LM2664 絶対最大 |
| **OK（実読で確認済み）** | 多数 | 下記各項 |

**最重要（これを直さないと初回起動しない可能性が高い）: B1。**
なお契約ネットリストの `NC` は**実ネットではなく未接続プレースホルダ**であることを確認済み（KiCad 側で該当 44 パッドの net は空文字、`(net "NC")` は 0 件）。ADS1299 の CLK/BIASREF/BIASIN/RESERVED と ESP32 GPIO が短絡している、という懸念は**否定された**。

---

## 1. ESP32-WROOM-32E 起動ストラップ ← **要対処（BOM のみ・銅箔変更なし）**

### 該当ネットリスト行
```
U_MCU   14  IO12   ADS_RESET_N     ← GPIO12 = MTDI（ストラップピン）
R_RST_UP 1      ADS_RESET_N
R_RST_UP 2      DVDD              ← 10kΩ で DVDD(3.3V) にプルアップ
C_RST_DLY 1     ADS_RESET_N
C_RST_DLY 2     GND               ← 100nF
U_ADS   36  RESET#  ADS_RESET_N
FB5     1       VDD_ESP / FB5 2 DVDD   ← DVDD は 3.3V（VDD_ESP からフェライト経由）
```

### 根拠（実読）
- ESP32 Series Datasheet v5.3 §3.2 <https://documentation.espressif.com/esp32_datasheet_en.pdf>
  - 「**MTDI = 0 (by default), VDD_SDIO pin is powered directly from VDD3P3_RTC. Typically this voltage is 3.3 V. MTDI = 1, VDD_SDIO pin is powered from internal 1.8 V LDO.**」
  - Table 3-1: MTDI の既定は **Pull-down / bit value 0**（内部プルダウン RPD **typ 45 kΩ**、Table 5-3）
  - Table 3-2 / Figure 3-1: **tSU ≥ 0 ms、tH ≥ 1 ms**。ストラップ値は CHIP_PU が VIH_nRST を超える前後で安定していなければならない
  - Table 5-3: **VIH = 0.75×VDD = 2.475 V**、**VIH_nRST = 0.75×VDD = 2.475 V**
  - 「The default values of all the above eFuse bits are 0, which means that **they are not burnt**」→ 工場出荷時に eFuse による上書きは**されていない**
- ESP32-WROOM-32E/32UE Datasheet v2.1 <https://documentation.espressif.com/esp32-wroom-32e_esp32-wroom-32ue_datasheet_en.pdf>
  - §4.2 に上記と同一の記述。Table 4 で MTDI = Pull-down
  - **Figure 9 (Peripheral Schematics) の注記に明記: 「IO12 should be kept low when the module is powered on.」** ← モジュールベンダ自身の設計ルール
  - Table 17 Flash Specifications: 3.3 V 品は **VCC 2.7–3.6 V**。VDD_SDIO=1.8 V ではフラッシュが動作しない
- 元設計 Cerelog も **GPIO12 を ADS1299 RESET# に使用**（`firmware/V1_ESP_EEG_firmware.ino`: `pin_RST_NUM = 12`）。ただし Cerelog 側に 10k プルアップがあるかは未確認（`hardware/schematic.pdf` は画像 PDF でテキスト抽出不可、レンダラ（poppler）が本環境に無く**未検証**）。**本基板が独自に追加した R_RST_UP が問題の原因**である可能性が高い（推測）。

### 判定: **要対処（indeterminate = 起動する個体としない個体が出る）**

タイミングを実数で解くと「確実に落ちる」でも「確実に通る」でもなく、**tH 規定を破る**：

| ノード | 回路 | 終値 | τ |
|---|---|---|---|
| ESP_EN | 10k↑3.3V + 100nF | 3.30 V | 1.00 ms |
| GPIO12 | 10k↑3.3V + 100nF + 内部 45k↓ | **2.70 V** | 0.818 ms |

- CHIP_PU が VIH_nRST(2.475 V) を超えるのは **t = 1.386 ms**
- その瞬間の GPIO12 = **2.204 V**（VIH 2.475 V 未満 → LOW）
- GPIO12 が VIH を超えるのは **t = 2.033 ms**、すなわち **CHIP_PU 解除の 0.65 ms 後**
- → **tH ≥ 1 ms のホールド窓の内側でストラップ値が LOW→HIGH に変化する = 規格違反**
- さらに GPIO12 の終値 2.70 V は VIH 下限 2.475 V に対し余裕 225 mV しかなく、RPD は typ 値のみで min/max 規定が無い

MTDI=1 とラッチされた個体は VDD_SDIO=1.8 V となり 3.3 V フラッシュを読めず、ROM ブートで `flash read err` → ブートループになる。

### 対処（**推奨案は 1 つ**）

**★ R_RST_UP を DNP（不実装）にする。BOM 1 行の変更のみ、銅箔変更ゼロ。**

- 結果: GPIO12 ノードは C_RST_DLY(100nF) + ESP32 内部 45kΩ プルダウンのみ → **tSU/tH の全区間で 0 V を保持 → MTDI = 0 確定 → VDD_SDIO = 3.3 V**
- 機能面の副作用なし: ADS1299 の RESET# はファームが push-pull で駆動する（Cerelog firmware は `pinMode(RST, OUTPUT)`）。ESP32 起動前は RESET# が Low = ADS1299 がリセット保持 = **むしろ望ましい初期状態**
- C_RST_DLY(100nF) は残置でよい（ストラップを Low に保つ役割として有効）。GPIO が 100nF を駆動する突入は CMOS 出力の自己電流制限内。気になれば 10nF 品への差し替えも可（任意）

**代替（採らない）**: RESET# を別 GPIO へ移設 → 銅箔変更＋ファーム改修が必要でコスト大。プルダウンへの変更 → ネット変更＝銅箔変更が必要。**DNP が最小・最安・最も安全。**

**保険（手順側）**: 万一 R_RST_UP を実装済みの基板を救済する場合は
`espefuse.py set-flash-voltage 3.3V`（XPD_SDIO_FORCE + XPD_SDIO_REG + XPD_SDIO_TIEH を焼く。以後「MTDI pin (GPIO12) is ignored」。**不可逆**）
根拠 <https://docs.espressif.com/projects/esptool/en/latest/esp32/espefuse/set-flash-voltage-cmd.html>

### 他のストラップピン（同資料 Table 3-1/3-3/3-4/3-5 で確認）

| ピン | 本基板 | 既定 | 判定 |
|---|---|---|---|
| GPIO0 | R_IO0_UP 10k↑VDD_ESP | Pull-up (1) | **OK** — SPI Boot |
| GPIO2 | R_IO2_DN 10k↓GND | Pull-down (0) | **OK** — GPIO0=1 なら GPIO2 は不問。書き込み時は両方 Low が必要で本回路で成立 |
| GPIO12/MTDI | 10k↑DVDD | Pull-down (0) | **NG（上記 B1）** |
| GPIO15/MTDO | R_IO15_DN 10k↓GND | Pull-up (1) | **注意** — Table 3-4 より **U0TXD Printing = Disabled**。ROM ブートログが出ない＝B1 由来の `flash read err` が見えない。**初号機のみ R_IO15_DN を DNP 推奨**（ESP_IO15 は他に接続なし、DNP で内部プルアップ＝ログ有効） |
| GPIO5 | R_CS_UP 10k↑DVDD | Pull-up (1) | **OK** — SDIO slave timing のみに影響。起動中 ADS1299 CS# が Deassert に保たれる利点あり |

補足: GPIO14(=ADS_START) は起動時に短時間トグルする既知挙動があるが、R_START_DN 10k↓ があり ADS1299 は未初期化なので無害（推測を含むが実害なし）。

---

## 2. 自動リセット回路（Q_EN / Q_IO0 / S8050 / DTR・RTS） ← **OK**

### 該当行
```
R_Q_EN_B  1 CH_DTR_N / 2 Q_EN_B     Q_EN  1 B Q_EN_B / 2 E CH_RTS_N / 3 C ESP_EN
R_Q_IO0_B 1 CH_RTS_N / 2 Q_IO0_B    Q_IO0 1 B Q_IO0_B / 2 E CH_DTR_N / 3 C ESP_IO0
U_USB 13 DTR# CH_DTR_N / U_USB 14 RTS# CH_RTS_N
```

**NodeMCU 型と完全に等価**（DTR→R→Q1.B, RTS→Q1.E, Q1.C→EN / RTS→R→Q2.B, DTR→Q2.E, Q2.C→IO0）。S8050 (SOT-23-3, J3Y) のピン配 1=B/2=E/3=C も一致。esptool の DTR/RTS シーケンスで書き込みモードに入れる。

**注意（実害小）**: CH340C は VCC=5 V 動作のため DTR#/RTS# は **0–5 V スイング**。片方 High・片方 Low の遷移時に S8050 の B-E 接合に約 5 V の逆電圧がかかる（V(BR)EBO 定格 5 V 近傍）。電流は 10kΩ で 0.5 mA 以下に制限され、破壊には至らない。書き込み時のみの過渡であり Rev.A は受容。OFF 時に 5 V が ESP32 の EN/IO0 へ回り込む経路は無いことを確認済み（B-E・B-C とも逆バイアス）。

---

## 3. CH340C ← **OK（全ピン一致）**

根拠: WCH CH340 Datasheet (I) v3B <https://docs.sparkfun.com/SparkFun_RTK_Facet_mosaic/assets/component_documentation/CH340DS1.PDF> §4 Pin definitions / §5.1

| ピン | 契約 | データシート | 判定 |
|---|---|---|---|
| 16 VCC | USB_5V | 「requires an external 0.1uF decoupling capacitor」→ C_USB_VCC 100nF あり | OK |
| 4 V3 | CH340_V3 + C_USB_V3 100nF→GND | 「**Connect to VCC when VCC is 3V3, connect to 0.1uF decoupling capacitor when VCC is 5V**」 | **OK（5V 動作なので 0.1µF が正解）** |
| 7 | NC | 「CH340C: No Connection, do not connect」 | OK |
| 8 (OUT#) | NC | 「CH340C: MODEM output IO」＝出力なので開放可 | OK |
| 15 R232 | GND | 「Assistant RS232 enable, **active high, integrated pull-down resistor**」 | **OK（GND = 通常 TTL モード）** |
| 5/6 UD+/UD− | USB_DP / USB_DM | 「connect to USB bus **directly, do not series resistors**」 | OK（直列抵抗なし。USBLC6 はシャント） |
| 2 TXD / 3 RXD | ESP_RXD / ESP_TXD | — | **OK（クロス結線が正しい）** |
| 9-12 CTS#/DSR#/RI#/DCD# | NC | 「**Unused I/O pins of CH340 should be NC**」 | OK |
| 7/8 水晶 | 不要 | 「CH340C … have integrated clock, **no external crystal required**」 | OK |

補足（無害）: 「DTR# pin of CH340G/C/T/K is used as a configuration input pin before the USB configuration completion」— 4.7kΩ プルダウンで大電流ディスクリプタを要求できるが、本基板は自動リセット網につながるのみ。ボード全体の VBUS 電流は CH340 のディスクリプタで制限されないため実害なし。

---

## 4. USB 入口 ← **OK**

### USBLC6-2SC6 のピン ← **一次資料で確認済み（Web 検索の回答は誤りだった）**
ST USBLC6-2 Doc ID 11265 Rev 5, Figure 1 Functional diagram (top view):
```
1  6      I/O1   I/O1
2  5      GND    VBUS
3  4      I/O2   I/O2
```
→ **Pin1 = I/O1, Pin2 = GND, Pin3 = I/O2, Pin4 = I/O2, Pin5 = VBUS, Pin6 = I/O1**

契約: `D_ESD 1 USB_DP / 2 GND / 3 USB_DM / 4 USB_DM / 5 USB_VBUS_RAW / 6 USB_DP` → **完全一致**。1&6 は内部で同一ノード（I/O1）、3&4 も同一（I/O2）なので、両方を同じネットに落とすのは正しい使い方。

> 途中の WebSearch は「Pin2=I/O1, Pin3=GND, Pin6=VBUS」と回答したが、ST の一次資料と矛盾するため**棄却**した。もし検索側が正しければ GND と D+ が短絡する致命傷になるため、一次資料での確認は必須だった。

### CC1/CC2
`R_CC1 5.1k → GND`, `R_CC2 5.1k → GND`（C23186, 5.1k 1%）→ UFP(Sink) 宣言として正しい。**OK**

### Polyfuse と全体電流
F1 = JK-NSMD050-13.2V（<https://jlcpcb.com/partdetail/C369159>）: **Ihold 0.5 A / Itrip 1 A / Ri min 150 mΩ / R1max 700 mΩ**

消費電流見積（WiFi/BT 未使用が前提。ファームは `Arduino.h`+`SPI.h` のみで RF を初期化しない）:

| 系統 | 内訳 | USB_5V 換算 |
|---|---|---|
| +3.3V (AMS1117) | ESP32 非 RF 約 40–70 mA（**推測: ESP32 DS は非 RF 時の値を表で示さないため実測必須**）+ ADS1299 IDVDD **1.0 mA**(実読) + AMS1117 接地電流 ~5 mA | ~76 mA |
| +2.5V (TLV70025) | ADS1299 IAVDD **7.14 mA**(実読, 8ch/bias off) | ~8 mA |
| −2.5V (LM2664→TPS72325) | AVSS ~8 mA、LM2664 効率 91% | ~9.5 mA |
| CH340C | ~12 mA | ~12 mA |
| **合計** | | **約 105 mA（typ）／140 mA（max）** |

→ Ihold 500 mA に対し 3.5 倍の余裕。**OK**。F1 の電圧降下は最悪 0.14 V（0.2 A × 0.7 Ω）で AMS1117 のヘッドルームに影響なし。

> **運用注意**: 消費が約 105 mA なので、低電流でオートオフするモバイルバッテリでは切れる可能性がある（多くは 50 mA 未満で切断なので通常は問題ないが要実機確認）。`08_simplified_power_design.md` §9 が想定した「LED で 30–50 mA 底上げ」は **B3 の通り実現していない**（実際は約 1.5 mA）。

---

## 5. 電源チェーン ← **OK（ピン配・EN 極性を一次資料で再確認）／一部注意**

### LM2664 ← **OK**
TI SNVS005E <https://www.ti.com/lit/ds/symlink/lm2664.pdf>

| ピン | データシート | 契約 | 判定 |
|---|---|---|---|
| 1 | GND | GND | OK |
| 2 | OUT | VNEG5 | OK |
| 3 | CAP− | LM_CAP_N | OK |
| 4 | SD 「**tie this pin to V+ in normal operation**」 | V5_LM_IN (=V+) | **OK（常時動作）** |
| 5 | V+ | V5_LM_IN | OK |
| 6 | CAP+ | LM_CAP_P | OK |

- IL = **40 mA** 定格に対し負荷 ~8 mA。ROUT max 25 Ω → 電圧降下 0.2 V → VNEG5 ≈ −4.8 V。TPS72325 のヘッドルーム十分。**OK**
- fSW = 40–80 kHz（fOSC の 1/2）。EEG 帯域外だが AVSS 経由の漏れは火入れ時に FFT で確認する（チェックリスト step 8）
- **N5 注意**: Abs Max「Supply voltage (V+ to GND) 5.8 V」。USB-C VBUS は規格上 5.5 V まで許容 → 余裕 0.3 V。USBLC6 の VBUS クランプは **VBR = 6 V min**（ST 実読）なので **LM2664 の絶対最大より上でしか効かない**。規格内では問題ないが、粗悪な 5 V 電源での過渡には無防備。Rev.B で USB_5V に 5.1 V 級 TVS 追加を推奨

### TPS72325 ← **OK（ECO-1#1 の正しさを確認）**
TI SLVS346E <https://www.ti.com/lit/ds/symlink/tps723.pdf>

- **DBV (SOT-23-5) ピン: 1=GND, 2=IN, 3=EN, 4=NR, 5=OUT** → 契約と**完全一致**
- EN: 「**Bipolar enable pin.** Driving this pin above the positive enable threshold **or below the negative enable threshold** turns on the regulator.」
  電気特性: **VEN(LO) = −1.5 V**（enable）、VDIS(HI)=+0.4 V / VDIS(LO)=−0.4 V（disable 窓）
  → 本基板 EN = V_NLDO_IN ≈ **−4.8 V** ≪ −1.5 V → **確実に enable**。**ECO-1#1 は正しい**
  （旧設計の EN=GND は −0.4〜+0.4 V の disable 窓ど真ん中 = 発注ストップ級バグだったことも裏付け）
- VEN 定格レンジ **−10 〜 +5.0 V** → −4.8 V は範囲内 **OK**
- CNR = **0.01 µF** 推奨 → C_NR 10nF（ECO-2#7）**一致 OK**
- CIN: 「An input capacitor is not required for LDO stability. However, an input capacitance with an effective value of **0.1 μF minimum** is recommended」→ C_NLDO_IN 1µF **OK**
- COUT: **2.2 〜 100 µF**、注記「**the effective capacitance is assumed to derate to 50% of the nominal**」

> **N2 注意**: C_NLDO_OUT = 2.2 µF **0402 6.3 V X5R**（C12530）。0402/6.3V 品は 2.5 V バイアスで大きくデレートし、実効 **0.9–1.3 µF** 程度になる（推測。メーカーの DC バイアス曲線は未取得）。単体では規定下限に届かない可能性がある。
> ただし AVSS ネットには **C_AVSS_B 10 µF 0603 + C_AVSS_H 100nF + C_AVSS_P17/P30/P37/P60 100nF×4** が並列に載っており、合計実効容量は十分（〜6 µF 以上）。**Rev.A は受容し、火入れ時に AVSS をオシロで発振確認**（チェックリスト step 5）。BOM 変更が安価なら C_NLDO_OUT を 0402 4.7 µF 品へ引き上げると確実。

### TLV70025 ← **OK**
TI SLVSA00E <https://www.ti.com/lit/ds/symlink/tlv700.pdf>

- 「**DDC Package 5-Pin SOT**」＝ SOT-23-5。ピン: **IN=1, GND=2, EN=3, NC=4, OUT=5** → 契約と**完全一致**
- EN: 「Driving EN over 0.9 V turns on the regulator」→ EN=V_PLDO_IN(5 V) で **常時 ON OK**
- CIN/COUT とも「a small, **1-μF** ceramic capacitor is recommended/needed」→ C_PLDO_IN / C_PLDO_OUT = 1 µF **完全一致 OK**
- NC ピン（4）: 「This pin can be tied to ground to improve thermal dissipation」→ 開放でも可 **OK**

> **BOM のデータ誤り**: `data/parts_lcsc.csv` の TLV70025 行の `package` 列が **`SOT-353`（= SC-70-5, 0.65 mm ピッチ）** になっている。TI の DDC は SOT-23-5（0.95 mm）であり、基板のフットプリント `SOT-23-5_L3.0-W1.7-P0.95` が**正しい**。MPN 列は `TLV70025DDCR` で正しいので実害はないが、**発注前に JLC の C19619 部品ページで実パッケージを目視確認すること**（万一 SC-70 品なら実装不能）。

### AMS1117 ← **注意（N3、Rev.A 受容）**
- ピン: 1=GND, 2=OUT, 3=IN, 4(tab)=OUT → 契約一致（`AMS1117 4 VOUT VDD_ESP`）**OK**
- 入出力: C_3V3_IN 1µF / C_3V3_OUT 10µF + C_3V3_B/B2 10µF×2 + C_3V3_M 1µF + C_3V3_H/H2 100nF×2 ≒ セラミック合計 30 µF 超
- **N3**: AMS1117 データシートは出力に **22 µF タンタル**を要求し、**ESR ≤ 0.5 Ω** を規定する（**二次情報**: 一次 PDF <https://mm.digikey.com/Volume0/opasdata/d220001/medias/docus/8122/AMS11173.3SOT223.pdf> はスキャン画像でテキスト抽出できず、本環境に OCR/レンダラが無いため**未検証**）。超低 ESR のセラミックのみだと発振する個体がある、というのが広く知られた挙動。
  → ECO の判断（「実績上動作する構成。発振兆候が出たら対処」）を踏襲し **Rev.A 受容**。火入れ時に VDD_ESP をオシロで確認（チェックリスト step 5）。発振したら C_3V3_OUT に 0.5–1 Ω を直列（手付け）で対処可能。

### フェライト
FB1–FB5 = GZ2012D601TF（0805, 600 Ω@100 MHz）。FB5 が **VDD_ESP → DVDD** を分離しており、DVDD は **3.3 V**。
→ `08_simplified_power_design.md` の「AVDD と DVDD は同じ +2.5 V」という記述は**現物と異なる（ドキュメントが陳腐化）**。そして **現物の方が正しい**（次項参照）。

---

## 6. ADS1299 電源・クロック・基準 ← **OK（DVDD=3.3V は TI 推奨構成に一致）**

根拠: TI SBAS499C <https://www.ti.com/lit/ds/symlink/ads1299.pdf>

### バイポーラ電源構成（§11.3 / Figure 78）
Figure 78「Bipolar Supply Operation」の推奨は **AVDD=+2.5 V / AVSS=−2.5 V / DVDD=+3.3 V**。本基板と一致。**OK**
Abs Max（§7.1）: AVDD−AVSS = −0.3〜**5.5 V**（本基板 5.0 V ✓）、DVDD−DGND = −0.3〜**3.9 V**（3.3 V ✓）、**AVSS to DGND = −3 〜 +0.2 V**（−2.5 V ✓、余裕 0.5 V）

### 外付け容量（§6 Pin Functions を実読）

| ピン | データシート指定 | 本基板 | 判定 |
|---|---|---|---|
| VCAP1 (28) | 「Connect a **100-μF** capacitor to AVSS」 | C_VCAP1 100µF 1206 + C_VCAP1_H 100nF | **OK**（ECO-3#11 は正しい） |
| VCAP2 (30) | 「**1-μF** to AVSS」 | C_VCAP2 1µF | **OK**（ECO-1#4） |
| VCAP3 (55) | 「parallel combination of **1-μF and 0.1-μF** to AVSS」 | C_VCAP3 1µF + C_VCAP3_H 100nF | **OK**（ECO-1#5） |
| VCAP4 (26) | 「**1-μF** to AVSS」 | C_VCAP4 1µF | OK |
| VREFP (24) | 「minimum **10-μF** capacitor to VREFN」 | C_VREFP_10u 10µF/25V + 100nF + 100pF、VREFN(25)=AVSS | **OK** |
| AVDD/DVDD | §11「Bypass each device supply with **10-μF and 0.1-μF**」 | AVDD/DVDD とも 10µF+100nF+個別 100nF | OK |
| RESV1 (31) | 「Reserved for future use, **connect directly to DGND**」 | GND 直結 | **OK**（ECO-1#2 は正しい） |
| DAISY_IN (41) | 「If not daisy-chaining devices, **tie DAISYIN directly to DGND**」 | GND 直結 | **OK** |
| BIASREF (60) | 未使用時は AVSS または開放。BIASREF_INT=1 で内部生成 | 開放 | **OK** |
| BIASIN (62) | 「can also float」 | 開放 | OK |
| NC (27,29) / RESERVED (64) | 「leave as open circuit」 | 開放 | OK |
| DRDY (47) | 「Pull DRDY to supply using weak pullup」 | R_DRDY_UP 10k↑DVDD | OK |

### クロック
- CLKSEL(52) = DVDD、CLK(37) = 開放
- Table 6「CLKSEL=1, CLK_EN=0 → 内部発振、**CLK PIN STATUS = 3-state**」
- CONFIG1 = 0x96（=リセット既定値）で **CLK_EN=0**（bit5）→ CLK は 3-state → **開放で OK**
- 内部発振 = **2.048 MHz**（typ、25 °C で ±0.5 %、−40〜85 °C で ±2.5 %）
- **既知の逸脱（Rev.A 受容、ECO 記載どおり）**: §6 の脚注(1) と §10.1.1 は「Set the two-state mode setting pins high to DVDD or low to DGND **through ≥10-kΩ resistors**」と規定。CLKSEL は直結。静的モードピンであり実害は小さいが、Rev.B で 10 kΩ 挿入。

### GPIO1–4（42/44/45/46）= GND 直結 ← **OK（ただしファーム制約あり → F3）**
データシートは自己矛盾している:
- §6 Pin Functions: 「Connect to DGND with a **≥10-kΩ resistor** if unused」
- §9.3.2.3: 「The GPIO pins are set as inputs after power-on or after a reset. **The pins should be shorted to DGND if not used.**」
- GPIO レジスタ(14h) reset = **0Fh**、GPIOC=1 が **入力** → **リセット後は 4 本とも入力**

→ 直結でも起動時は競合しない。**ただし GPIOC ビットを 0（出力）にして GPIOD を 1 にすると GND に対する恒常的な短絡になる**。Cerelog firmware は 0x14 を書かない（書き込みは 0x01–0x02, 0x05–0x0F, 0x15–0x17）ことを確認済み。→ **F3 としてファーム側の禁止事項に明記する。**

### 電源投入順序とリセット（§11.1）← **要対処（F2）**
実読:
> 「Before device power up, all digital and analog inputs must be low. ... Allow time for the supply voltages to reach their final value, and then begin supplying the master clock signal to the CLK pin. **Wait for time tPOR, then transmit a reset pulse using either the RESET pin or RESET command** to initialize the digital portion of the chip. **Issue the reset after tPOR or after the VCAP1 voltage is greater than 1.1 V, whichever time is longer.**」
> Table 30: **tPOR = 2^18 tCLK**、tRST = 2 tCLK

- tPOR = 2^18 / 2.048 MHz = **128 ms**
- Figure 67（Initial Flow at Power-Up）: 「If VCAP1 < 1.1 V at tPOR, continue waiting until VCAP1 ≥ 1.1 V」

**Cerelog firmware の実シーケンス**（実読）:
```
PWDN=LOW; RST=LOW; delay(100ms); PWDN=HIGH; RST=HIGH; delay(1000ms);
```
→ **RESET# を PWDN# と同時に解放している＝ tPOR 後のリセットパルスが存在しない**。§11.1 に非適合。

さらに **ECO-3#11 で C_VCAP1 を 1 µF → 100 µF に増やした**ため、VCAP1 の充電時間は約 100 倍になる。1000 ms で足りるかは TI が VCAP1 の内部駆動インピーダンスを公表していないため**計算では確定できない（要実測）**。

→ **F2**: ファームで「PWDN/RESET を High にして 1000 ms 待機 → **RESET# を再度 Low に 10 µs 以上 → High** →（または RESET コマンド 0x06 送出）→ 18 tCLK(≈9 µs) 待ち → SDATAC → ID 読み出し」に変更。加えて **火入れ時に VCAP1(pin 28) を AVSS 基準でオシロ観測し、1.1 V 到達時刻を実測**（チェックリスト step 6）。実測値が 1000 ms を超えるようなら待機時間を延長する。

### 電源投入時の「全デジタル入力 Low」要求
PWDN#/CS#/RESET# は DVDD へプルアップされているが、**プルアップ先が DVDD 自身**なので DVDD より高い電圧が印加されることはなく、ESD ダイオードの順バイアスは起こらない。TI の要求趣旨（自電源より高い入力を避ける）は満たされる。**OK**

---

## 7. アナログ入力段・BIAS ← **概ね OK／N1 注意**

### 入力ネットワーク
各 ch: 電極 → 10 kΩ 直列（R_INxP / R_INxN, 0402 1%）→ C_DIF 10 nF（**0805 NP0/C0G**, C237168）を差動に、C_CM 1 nF（0603 X7R）を各ノード→GND。

- ADS1299 §12.1: 「Analog inputs with differential connections must have a capacitor placed differentially across the inputs. The differential capacitors must be of high quality. **The best ceramic chip capacitors are C0G (NPO)**」→ **C_DIF が C0G なのは要求どおり OK**（ECO-2#6 が正しい）
- 差動カットオフ ≈ 1/(2π·20 kΩ·(10 nF + 1 nF/2)) ≈ **758 Hz**。ADS1299 の変調器 fMOD = fCLK/2 = 1.024 MHz に対し −62 dB → **アンチエイリアスとして十分 OK**
- C_CM が X7R ±10 % のため 50 Hz CMRR は外部網律速で **70 dB 前後**（ECO の見積 64 dB と同オーダー）。**Rev.A 受容（ECO 記載どおり）**、実測で不足なら対処

### SRB / 参照電極
```
R_SRB_SER (0Ω)  A2_ELEC ── SRB1ネット
U_ADS 17 SRB1 = SRB1 / U_ADS 18 SRB2 = SRB1      ← SRB1・SRB2 を束ね
R_IN1N,2N,3N,5N,6N,7N,8N (10k)  SRB1 ── INxN     ← ch4 以外の N 側を外部で SRB1 に接続
R_IN4N (10k)  ECGN_ELEC ── IN4N                  ← ch4 のみ真の差動（ECG）
```
- ADS1299 §6: SRB1/SRB2 は「Patient stimulus, reference, and bias signal」。束ねは電気的に問題なし。**OK**
- **ECG は ch4**（J2 pin4=ECGP→IN4P, pin5=ECGN→IN4N）。`02_firmware_analysis.md` の「CH3SET = 0x20 (bipolar ECG)」は**現物と不一致**（ドキュメントが陳腐化）→ **F1 に含める**

### BIAS（DRL）ループ ← **N1 注意**
```
U_ADS 63 BIASOUT = BIAS_OUT_INT
R_BIAS_SER (1MΩ)  BIAS_OUT_INT ── A1_ELEC        ← BIAS 電極へ
R_BIAS_FB  (1MΩ)  BIAS_INV ── BIAS_OUT_INT       ← 帰還抵抗
C_BIAS_INV (100nF) BIAS_INV ── GND               ← ★ ここが TI 推奨と異なる
U_ADS 61 BIASINV = BIAS_INV / 60 BIASREF = 開放 / 62 BIASIN = 開放
```
- TI **Figure 68**（Setting Common-Mode Using BIAS Electrode）の推奨定数は **1 MΩ と 1.5 nF**、いずれも BIASOUT–BIASINV 間（帰還経路）に置かれる構成。
- 本基板は 1 MΩ は帰還経路で正しいが、**容量は BIASINV → GND（加算節点→GND）に 100 nF** で入っている。
- 反転アンプの一般論として、帰還に並列の C は高域利得を落として**安定化**、加算節点→GND の C は雑音利得を持ち上げて**不安定化**方向に働く。TI も §9.3.2.4.5 で「**Stabilizing the entire loop is specific to the individual user system based on the various poles in the loop.**」「All the amplifier terminals are available at the pins, allowing the user to choose the components for the feedback loop」と、ループ安定化は設計者責任と明記している。
- なお AVDD/AVSS = ±2.5 V なので **GND = 中点電位 = BIASREF 内部基準と同電位**であり、容量の落とし先が GND であること自体は正しい。問題は**位置（帰還ではなく加算節点）と値（100 nF vs 1.5 nF）**。
- 100 nF・1 MΩ で考えると極は約 **1.6 Hz** となり、1.5 nF 相当（約 106 Hz）に比べ DRL ループ帯域が桁で狭い。50 Hz の同相除去に対する DRL の寄与はほぼ失われる。

**判定: Rev.A は「注意」。発振すれば全 ch にノイズが乗るため、火入れで必ず確認する。**

対処（安い順）:
1. **BOM のみ**: C_BIAS_INV を **DNP**。加算節点の容量を除去し、不安定化要素を無くす（ループは 1 MΩ 帰還のみ）
2. 発振または 50 Hz 除去不足が実測されたら、**R_BIAS_FB(0805) の上に 1.5 nF（0402）を手付けで並列**に載せて TI Figure 68 に一致させる
3. Rev.B で C を帰還経路（BIAS_INV–BIAS_OUT_INT）へ移設し 1.5 nF に変更（銅箔変更）

### 未使用 ch
§6 脚注(2)「Connect unused analog inputs directly to AVDD」／§10.1.1「Power down unused analog inputs and connect them directly to AVDD」。
本基板は 8 ch すべて J2 に配線されており、未使用 ch は電極未接続＝開放になる。→ **F1 で CHnSET = 0x81（power-down + MUX short）に設定して内部 MUX で切り離す**ことで対処（外部結線の変更は不要）。

---

## 8. SPI / 制御線 ← **OK**

| 信号 | ESP32 | 契約ネット | Cerelog firmware（実読） | 判定 |
|---|---|---|---|---|
| SCLK | GPIO18 (pin30) | SPI_SCK →R_SCLK 0Ω→ ADS_SCLK_LOC → ADS pin40 | `pin_SCK_NUM = 18` | OK |
| MOSI | GPIO23 (pin37) | SPI_MOSI →R_MOSI 0Ω→ ADS_DIN_LOC → ADS pin34 | `pin_MOSI_NUM = 23` | OK |
| MISO | GPIO19 (pin31) | SPI_MISO ←R_MISO 0Ω← ADS_DOUT_LOC ← ADS pin43 | `pin_MISO_NUM = 19` | OK |
| CS# | GPIO5 (pin29) | ADS_CS_N, R_CS_UP 10k↑DVDD, ADS pin39 | `pin_CS_NUM = 5` | OK |
| PWDN# | GPIO13 (pin16) | ADS_PWDN_N, R_PWDN_UP 10k↑DVDD, ADS pin35 | `pin_PWDN_NUM = 13` | OK |
| RESET# | GPIO12 (pin14) | ADS_RESET_N, R_RST_UP 10k↑DVDD, ADS pin36 | `pin_RST_NUM = 12` | **配線 OK / B1 で R_RST_UP を DNP** |
| START | GPIO14 (pin13) | ADS_START, R_START_DN 10k↓GND, ADS pin38 | `pin_START_NUM = 14` | OK |
| DRDY# | GPIO27 (pin12) | ADS_DRDY_N, R_DRDY_UP 10k↑DVDD, ADS pin47 | `pin_DRDY_NUM = 27`、FALLING 割込 | OK |
| LED | GPIO17 (pin28) | STATUS_LED_DRV | `pin_LED_DEBUG = 17` | 配線 OK（B3 参照） |

**VSPI 既定ピン（18/23/19/5）と firmware 定義が完全一致。** SPI 設定は 4 MHz / SPI_MODE1 / MSBFIRST（実読）。

論理レベル: ESP32 VOH min = 0.8×VDD = **2.64 V**、ADS1299 VIH min = 0.8×DVDD = **2.64 V**。数値上は余裕ゼロだが、DVDD は VDD_ESP から FB5(DCR 数十 mΩ)経由で**わずかに低い**ため実効的には順方向のマージンがある。同一レールなので温度・電圧変動でも追従する。**OK**（懸念なし）

---

## 9. ステータス LED ← **要対処（B3、BOM のみ）**

```
U_MCU 28 IO17 → STATUS_LED_DRV → R_LED(330Ω, C23138) → LED_A → D_LED(A→C) → GND
```
D_LED = **C72043 / Everlight 19-217/GHC-YR1S2/3T**（<https://jlcpcb.com/partdetail/C72043>）
実測データ: **package = 0603**、**Emerald Green、518 nm、Vf = 3.3 V @20 mA、199 mcd**

- **フットプリント整合は OK**: 基板は `LED0603-RD`（パッド 0.8×0.8 mm、中心間 1.5 mm）で **0603 品と一致**。`data/parts_lcsc.csv` の `package` 列の「0805」が**誤記**（実害なし、CSV の修正のみ）
- **電流が足りない**: 電源が 3.3 V、LED の Vf が 3.3 V(@20 mA)。ESP32 の VOH min は 2.64 V。330 Ω では動作点が Vf(I)+330·I = 約 3.2 V となり **I ≈ 1.5 mA**（緑 InGaN の低電流域 Vf ≈ 2.7 V として。**推測を含む — 実測で確認**）。輝度は約 15 mcd 相当で暗い
- `08_simplified_power_design.md` §9 の「LED で 30–50 mA のダミー負荷を作りモバイルバッテリの自動オフを防ぐ」は **完全に未達**（1.5 mA）

**対処: R_LED を 330 Ω → 100 Ω に変更（BOM 1 行、0603 同フットプリント）。** 約 4–5 mA になり視認性が確保される。
より確実にしたい場合は D_LED を Vf ≈ 2.0 V の赤/黄 0603 LED に差し替える（330 Ω のままで約 4 mA）。
**モバイルバッテリ対策は LED では解決しないので、運用側で「PC の USB ポートか、オートオフしない/低電流モードのあるバッテリを使う」と決めること。**

---

## 10. JLC 実装上の注意 ← **要対処（J1、発注フローのみ）**

根拠 <https://jlcpcb.com/capabilities/pcb-assembly-capabilities>

| 項目 | 本基板 | JLC 能力 | 判定 |
|---|---|---|---|
| 最小受動部品 | 0402（R_INxP/N ほか） | Economic **0402** / Standard **0201** | **OK（Economic で可）** |
| QFP ピッチ | U_ADS TQFP-64 **0.50 mm**（パッド 0.28×1.8 mm、パッド間 0.22 mm） | Economic **0.40 mm** / Standard 0.35 mm | **OK（Economic で可）** |
| THT | J2（2×6 ピンヘッダ、φ1.524 スルーホール） | 両サービスとも THT / 混載対応 | OK |
| ESP32 モジュール EPAD | U_MCU = 47 パッド（信号 38 + EPAD 9 分割） | — | **OK**。WROOM-32E DS §9「Soldering the EPAD to the ground of the base board **is not a must**, however, it can optimize thermal performance」→ 9 分割は推奨ランドパターン準拠 |
| **基板サイズ** | **61.8 × 45 mm** | **Standard PCBA は単板 70×70 mm 以上**／Economic は 10×10 mm から／パネル化は両方 10×10–250×250 mm | **要対処 J1** |
| USB-C のペグ穴/スロット | J1 = `TYPE-C-16PIN-2MD(073)`、位置決めペグ NPTH あり | 明記なし | ECO の **L4** で既にレイアウト修理項目として管理中。**本レビューでは再掲のみ** |

**J1 の対処**: 61.8×45 mm は **Standard PCBA の単板最小 70×70 mm を下回る**。
→ **(a) Economic PCBA で発注する**（部品要件はすべて Economic の範囲内なのでこれが最短）、または **(b) 2×2 等にパネル化して Standard PCBA を使う**。
どちらでも技術的に成立するが、**発注操作の前に JLC の見積画面でサービス種別と最小サイズを必ず確認する**こと（能力ページの記載は改定されうるため）。
なお Economic は「Gold Fingers/Castellated Holes/Edge Plating」非対応と記載があるが、これは**基板側の加工**の話であり、キャスタレーション付き**モジュールの実装**を禁じるものではない（推測。見積時に確認を推奨）。

---

## 11. その他（レイアウト担当への申し送り）

### デカップリングコンデンサの designator が実ピン番号と一致していない ← **レイアウトで要注意**
`C_AVDD_P3 / P19 / P31 / P36 / P59 / P64`、`C_AVSS_P17 / P30 / P37 / P60`、`C_DVDD_P40 / P58` は名前が「Pnn = ピン番号」に見えるが、ADS1299 の実際の電源ピンは:
- **AVDD: 19, 21, 22, 56, 59**（AVDD1 = 54）
- **AVSS: 20, 23, 32, 57, 58**（AVSS1 = 53）
- **DVDD: 48, 50**（DGND = 33, 49, 51）

一致するのは P19 と P59 のみ。**C_AVSS_P17/P30/P37/P60 と C_DVDD_P40/P58 はどれも該当ピンではない**（pin17=SRB1, 30=VCAP2, 37=CLK, 40=SCLK, 58=AVSS, 60=BIASREF）。
→ **配置は designator の名前ではなく、上の実ピン番号に従って行うこと。** ネット接続自体は正しいので、電気的な誤りではない。

### 星型接続（§11）
「star connect **AVDD1 to the AVDD pins** and **AVSS1 to the AVSS pins**」「Place the capacitors for supply, reference, and VCAP1 to VCAP4 **as close to the package as possible**」「Do not place vias between bypass capacitors and the active device」。VCAP1 は 100 µF/1206 と大きいので、極力 IC 直近に置く。

### CHASSIS_GND が浮いている ← **N4（Rev.A 受容だが要認識）**
`CHASSIS_GND` に接続されているのは **J1 pin13/14（SHELL）と J2 pin12 のみ**で、GND との間に抵抗・容量・ビーズが**1 つも無い**（`08_simplified_power_design.md` は「EMI ビーズで 1 点接続」と書いているが、実回路には存在しない）。

含意:
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

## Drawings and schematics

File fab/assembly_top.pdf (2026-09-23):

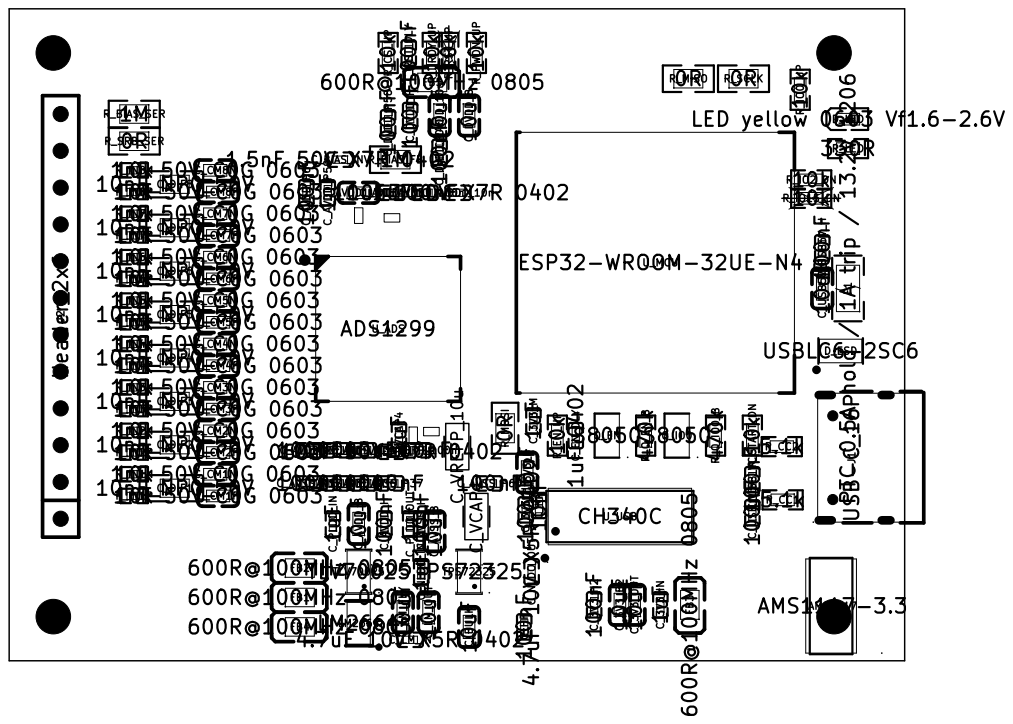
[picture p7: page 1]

Size: A4 | Rev:
KiCad E.D.A. 10.0.5 | Id: 1/1

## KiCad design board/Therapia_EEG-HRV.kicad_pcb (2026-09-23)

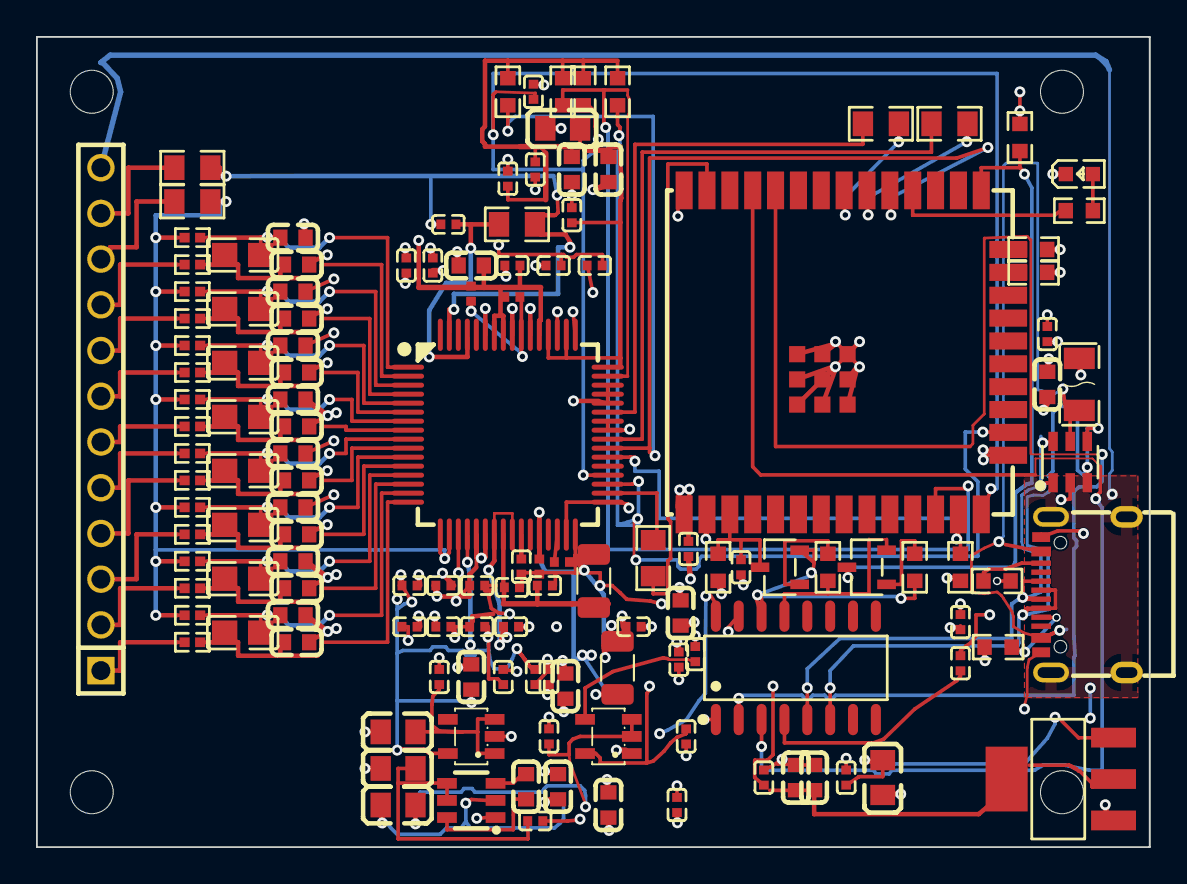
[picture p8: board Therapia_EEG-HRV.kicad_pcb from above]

Board: 4 copper layers, 61.8 x 45.0 mm, 141 parts (0 on the bottom side), 79 nets.

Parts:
AMS1117: AMS1117-3.3; SOT-223-3_L6.5-W3.4-P2.30-LS7.0-BR
C_3V3_B, C_3V3_B2, C_3V3_OUT: 10uF; C0603
C_3V3_H, C_3V3_H2: 100nF; C0402
C_3V3_IN, C_3V3_M: 1uF; C0402
C_AVDD1_1u: 1uF; C0402
C_AVDD1_10n: 10nF 50V X7R 0402; C0402
C_AVDD1_10u: 10uF; C0603
C_AVDD1_100n: 100nF; C0402
C_AVDD_B: 10uF; C0603
C_AVDD_H: 100nF; C0402
C_AVDD_P3, C_AVDD_P19, C_AVDD_P31, C_AVDD_P36, C_AVDD_P64: 100nF; C0402
C_AVDD_P59: 1uF; C0402
C_AVSS_B: 10uF; C0603
C_AVSS_H: 100nF; C0402
C_AVSS_P17, C_AVSS_P30, C_AVSS_P37, C_AVSS_P60: 100nF; C0402
C_BIAS_INV: 1.5nF 50V X7R 0402; C0402
C_BULK: 10uF; C0603
C_CM1N, C_CM1P, C_CM2N, C_CM2P, C_CM3N, C_CM3P, C_CM4N, C_CM4P, C_CM5N, C_CM5P, C_CM6N, C_CM6P, C_CM7N, C_CM7P, C_CM8N, C_CM8P: 1nF 50V C0G 0603; C0603
C_DIF1, C_DIF2, C_DIF3, C_DIF4, C_DIF5, C_DIF6, C_DIF7, C_DIF8: 10nF_NP0_50V; C0805
C_DVDD_10u: 10uF; C0603
C_DVDD_B: 10uF; C0603
C_DVDD_H: 100nF; C0402
C_DVDD_P40, C_DVDD_P58: 100nF; C0402
C_EN_DLY: 1uF 0402; C0402
C_HF: 100nF; C0402
C_LM_FLY: 10uF; C0603
C_LM_IN: 4.7uF 10V X5R 0402; C0402
C_LM_OUT: 10uF; C0603
C_NLDO_IN: 1uF; C0402
C_NLDO_OUT: 4.7uF 10V X5R 0402; C0402
C_NR: 10nF; C0402
C_PLDO_IN: 1uF; C0402
C_PLDO_OUT: 1uF; C0402
C_RST_DLY: 100nF; C0402
C_USB5V_B: 10uF; C0603
C_USB5V_H: 100nF; C0402
C_USB_V3: 100nF; C0402
C_USB_VCC: 100nF; C0402
C_VCAP1: 100uF; C_1206_3216Metric
C_VCAP1_H, C_VCAP3_H: 100nF; C0402
C_VCAP2, C_VCAP3, C_VCAP4: 1uF; C0402
C_VREFP_10n: 10nF 50V X7R 0402; C0402
C_VREFP_10u: 10uF 50V X5R 1206; C_1206_3216Metric
C_VREFP_100n: 100nF; C0402
D_ESD: USBLC6-2SC6; SOT-23-6_L2.9-W1.6-P0.95-LS2.8-BL
D_LED: LED yellow 0603 Vf1.6-2.6V; LED0603-RD
F1: PTC 0.5A hold / 1A trip / 13.2V 1206; F1206
FB1, FB2, FB3, FB4, FB5: 600R@100MHz 0805; L0805
H1: NPTH_2.3876mm_M2; Pad_e525
H2: NPTH_2.3876mm_M2; Pad_e526
H3: NPTH_2.3876mm_M2; Pad_e527
H4: NPTH_2.3876mm_M2; Pad_e528
J1: USB-C_16P; USB-C-SMD_TYPE-C-6PIN-2MD-073
J2: Header_2x6; HDR-TH_12P-P2.54-V-M
LM2664: LM2664; SOT-23-6_L2.9-W1.6-P0.95-LS2.8-BR
PEG1, PEG2: NPTH_0.7000mm_peg; NPTH_0.7mm_USB-C_peg
Q_EN: S8050; SOT-23-3_L3.0-W1.7-P0.95-LS2.9-BR
Q_IO0: S8050; SOT-23-3_L3.0-W1.7-P0.95-LS2.9-BR
R_BIAS_FB: 1M; R0805
R_BIAS_SER: 1M; R0805
R_CC1, R_CC2: 5.1k; R0603
R_CS_UP: 10k; R0603
R_DRDY_UP: 10k; R0603
R_EN_UP: 10k; R0603
R_IN1N, R_IN1P, R_IN2N, R_IN2P, R_IN3N, R_IN3P, R_IN4N, R_IN4P, R_IN5N, R_IN5P, R_IN6N, R_IN6P, R_IN7N, R_IN7P, R_IN8N, R_IN8P: 10k; R0402
R_IO0_UP, R_IO2_DN, R_IO15_DN: 10k; R0603
R_LED: 330R; R0603
R_MISO: 0R; R0805
R_MOSI: 0R; R0805
R_PWDN_UP: 10k; R0603
R_Q_EN_B: 470k; R0603
R_Q_IO0_B: 470k; R0603
R_RST_UP: 10k; R0603
R_SCLK: 0R; R0805
R_SRB_SER: 0R; R0805
R_START_DN: 10k; R0603
TLV70025: TLV70025; SOT-23-5_L3.0-W1.7-P0.95-LS2.8-BR
TPS72325: TPS72325; SOT-23-5_L3.0-W1.7-P0.95-LS2.8-BR
U_ADS: ADS1299; TQFP-64_L10.0-W10.0-P0.50-LS12.0-TL
U_MCU: ESP32-WROOM-32UE-N4; WIFI-SMD_ESP32-WROOM-32E
U_USB: CH340C; SOP-16_L10.0-W3.9-P1.27-LS6.0-BL

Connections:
A1_ELEC: J2.11, R_BIAS_SER.2
A2_ELEC: J2.10, R_SRB_SER.2
ADS_CS_N: R_CS_UP.1, U_ADS.39, U_MCU.29
ADS_DIN_LOC: R_MOSI.1, U_ADS.34
ADS_DOUT_LOC: R_MISO.1, U_ADS.43
ADS_DRDY_N: R_DRDY_UP.1, U_ADS.47, U_MCU.12
ADS_PWDN_N: R_PWDN_UP.1, U_ADS.35, U_MCU.16
ADS_RESET_N: C_RST_DLY.1, R_RST_UP.1, U_ADS.36, U_MCU.14
ADS_SCLK_LOC: R_SCLK.1, U_ADS.40
ADS_START: R_START_DN.1, U_ADS.38, U_MCU.13
AVDD: C_AVDD1_1u.1, C_AVDD1_10n.1, C_AVDD1_10u.1, C_AVDD1_100n.1, C_AVDD_B.1, C_AVDD_H.1, C_AVDD_P3.1, C_AVDD_P19.1, C_AVDD_P31.1, C_AVDD_P36.1, C_AVDD_P59.1, C_AVDD_P64.1, C_PLDO_OUT.2, TLV70025.5, U_ADS.19, U_ADS.21, U_ADS.22, U_ADS.54, U_ADS.56, U_ADS.59
AVSS: C_AVDD1_1u.2, C_AVDD1_10n.2, C_AVDD1_10u.2, C_AVDD1_100n.2, C_AVSS_B.1, C_AVSS_H.1, C_AVSS_P17.1, C_AVSS_P30.1, C_AVSS_P37.1, C_AVSS_P60.1, C_NLDO_OUT.2, C_VCAP1.2, C_VCAP1_H.2, C_VCAP2.2, C_VCAP3.2, C_VCAP3_H.2, C_VCAP4.2, C_VREFP_10n.2, C_VREFP_10u.2, C_VREFP_100n.2, TPS72325.5, U_ADS.20, U_ADS.23, U_ADS.25, U_ADS.32, U_ADS.53, U_ADS.57, U_ADS.58
BIAS_INV: C_BIAS_INV.1, R_BIAS_FB.1, U_ADS.61
BIAS_OUT_INT: C_BIAS_INV.2, R_BIAS_FB.2, R_BIAS_SER.1, U_ADS.63
CH3_ELEC: J2.3, R_IN3P.1
CH5_ELEC: J2.6, R_IN5P.1
CH6_ELEC: J2.7, R_IN6P.1
CH7_ELEC: J2.8, R_IN7P.1
CH8_ELEC: J2.9, R_IN8P.1
CH340_V3: C_USB_V3.1, U_USB.4
CHASSIS_GND: J1.13, J1.14, J2.12
CH_DTR_N: Q_IO0.2, R_Q_EN_B.1, U_USB.13
CH_RTS_N: Q_EN.2, R_Q_IO0_B.1, U_USB.14
DVDD: C_DVDD_10u.1, C_DVDD_B.1, C_DVDD_H.1, C_DVDD_P40.1, C_DVDD_P58.1, FB5.2, R_CS_UP.2, R_DRDY_UP.2, R_PWDN_UP.2, R_RST_UP.2, U_ADS.48, U_ADS.50, U_ADS.52
ECGN_ELEC: J2.5, R_IN4N.1
ECGP_ELEC: J2.4, R_IN4P.1
ESP_EN: C_EN_DLY.1, Q_EN.3, R_EN_UP.2, U_MCU.3
ESP_IO0: Q_IO0.3, R_IO0_UP.2, U_MCU.25
ESP_IO2: R_IO2_DN.1, U_MCU.24
ESP_IO15: R_IO15_DN.1, U_MCU.23
ESP_RXD: U_MCU.34, U_USB.2
ESP_TXD: U_MCU.35, U_USB.3
FP1_ELEC: J2.1, R_IN1P.1
FP2_ELEC: J2.2, R_IN2P.1
GND: AMS1117.1, C_3V3_B.2, C_3V3_B2.2, C_3V3_H.2, C_3V3_H2.2, C_3V3_IN.2, C_3V3_M.2, C_3V3_OUT.2, C_AVDD_B.2, C_AVDD_H.2, C_AVDD_P3.2, C_AVDD_P19.2, C_AVDD_P31.2, C_AVDD_P36.2, C_AVDD_P59.2, C_AVDD_P64.2, C_AVSS_B.2, C_AVSS_H.2, C_AVSS_P17.2, C_AVSS_P30.2, C_AVSS_P37.2, C_AVSS_P60.2, C_BULK.2, C_CM1N.2, C_CM1P.2, C_CM2N.2, C_CM2P.2, C_CM3N.2, C_CM3P.2, C_CM4N.2, C_CM4P.2, C_CM5N.2, C_CM5P.2, C_CM6N.2, C_CM6P.2, C_CM7N.2, C_CM7P.2, C_CM8N.2, C_CM8P.2, C_DVDD_10u.2, C_DVDD_B.2, C_DVDD_H.2, C_DVDD_P40.2, C_DVDD_P58.2, C_EN_DLY.2, C_HF.2, C_LM_IN.2, C_LM_OUT.2, C_NLDO_IN.2, C_NLDO_OUT.1, C_NR.2, C_PLDO_IN.2, C_PLDO_OUT.1, C_RST_DLY.2, C_USB5V_B.2, C_USB5V_H.2, C_USB_V3.2, C_USB_VCC.2, D_ESD.2, D_LED.1, J1.1, J1.12, LM2664.1, R_CC1.2, R_CC2.2, R_IO2_DN.2, R_IO15_DN.2, R_START_DN.2, TLV70025.2, TPS72325.1, U_ADS.31, U_ADS.33, U_ADS.41, U_ADS.42, U_ADS.44, U_ADS.45, U_ADS.46, U_ADS.49, U_ADS.51, U_MCU.1, U_MCU.15, U_MCU.38, U_MCU.39, U_USB.1, U_USB.15
IN1N: C_CM1N.1, C_DIF1.2, R_IN1N.2, U_ADS.15
IN1P: C_CM1P.1, C_DIF1.1, R_IN1P.2, U_ADS.16
IN2N: C_CM2N.1, C_DIF2.2, R_IN2N.2, U_ADS.13
IN2P: C_CM2P.1, C_DIF2.1, R_IN2P.2, U_ADS.14
IN3N: C_CM3N.1, C_DIF3.2, R_IN3N.2, U_ADS.11
IN3P: C_CM3P.1, C_DIF3.1, R_IN3P.2, U_ADS.12
IN4N: C_CM4N.1, C_DIF4.2, R_IN4N.2, U_ADS.9
IN4P: C_CM4P.1, C_DIF4.1, R_IN4P.2, U_ADS.10
IN5N: C_CM5N.1, C_DIF5.2, R_IN5N.2, U_ADS.7
IN5P: C_CM5P.1, C_DIF5.1, R_IN5P.2, U_ADS.8
IN6N: C_CM6N.1, C_DIF6.2, R_IN6N.2, U_ADS.5
IN6P: C_CM6P.1, C_DIF6.1, R_IN6P.2, U_ADS.6
IN7N: C_CM7N.1, C_DIF7.2, R_IN7N.2, U_ADS.3
IN7P: C_CM7P.1, C_DIF7.1, R_IN7P.2, U_ADS.4
IN8N: C_CM8N.1, C_DIF8.2, R_IN8N.2, U_ADS.1
IN8P: C_CM8P.1, C_DIF8.1, R_IN8P.2, U_ADS.2
LED_A: D_LED.2, R_LED.2
LM_CAP_N: C_LM_FLY.2, LM2664.3
LM_CAP_P: C_LM_FLY.1, LM2664.6
Q_EN_B: Q_EN.1, R_Q_EN_B.2
Q_IO0_B: Q_IO0.1, R_Q_IO0_B.2
SPI_MISO: R_MISO.2, U_MCU.31
SPI_MOSI: R_MOSI.2, U_MCU.37
SPI_SCK: R_SCLK.2, U_MCU.30
SRB1: R_IN1N.1, R_IN2N.1, R_IN3N.1, R_IN5N.1, R_IN6N.1, R_IN7N.1, R_IN8N.1, R_SRB_SER.1, U_ADS.17, U_ADS.18
STATUS_LED_DRV: R_LED.1, U_MCU.28
TPS_NR: C_NR.1, TPS72325.4
USB_5V: C_BULK.1, C_HF.1, C_USB5V_B.1, C_USB5V_H.1, C_USB_VCC.1, F1.2, FB1.1, FB2.1, FB3.1, U_USB.16
USB_CC1: J1.4, R_CC1.1
USB_CC2: J1.10, R_CC2.1
USB_DM: D_ESD.3, D_ESD.4, J1.5, J1.7, U_USB.6
USB_DP: D_ESD.1, D_ESD.6, J1.6, J1.8, U_USB.5
USB_VBUS_RAW: D_ESD.5, F1.1, J1.2, J1.11
V5_LM_IN: C_LM_IN.1, FB1.2, LM2664.4, LM2664.5
VCAP1: C_VCAP1.1, C_VCAP1_H.1, U_ADS.28
VCAP2: C_VCAP2.1, U_ADS.30
VCAP3: C_VCAP3.1, C_VCAP3_H.1, U_ADS.55
VCAP4: C_VCAP4.1, U_ADS.26
VDD_ESP: AMS1117.2, AMS1117.4, C_3V3_B.1, C_3V3_B2.1, C_3V3_H.1, C_3V3_H2.1, C_3V3_M.1, C_3V3_OUT.1, FB5.1, R_EN_UP.1, R_IO0_UP.1, U_MCU.2
VNEG5: C_LM_OUT.1, FB4.1, LM2664.2
VREFP: C_VREFP_10n.1, C_VREFP_10u.1, C_VREFP_100n.1, U_ADS.24
V_3V3_IN: AMS1117.3, C_3V3_IN.1, FB3.2
V_NLDO_IN: C_NLDO_IN.1, FB4.2, TPS72325.2, TPS72325.3
V_PLDO_IN: C_PLDO_IN.1, FB2.2, TLV70025.1, TLV70025.3

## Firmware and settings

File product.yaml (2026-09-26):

# Generated by `python3 -m pcbharness.core.tools.scaffold_manifest`.
#
# Every value under `provenance:` was copied from the file named there, and the
# S0_manifest gate re-reads that file on every run and fails if the two disagree.
# Change the original, then re-run the scaffolder; do not edit the copy.
#
# Values NOT listed in `provenance:` are decisions recorded here and nowhere else.
#
# Product: Therapia EEG-HRV (Cerelog-derived), Rev.A_Y9, not manufactured (see status).
# No order_spec.json or mech_contract.json exists for this revision, so every
# value below with provenance comes from a script constant.

schema: therapia-pcb-harness/product/1
product:
  name: brain_canvas
  title: Therapia EEG-HRV (Cerelog-derived)
  revision: Rev.A_Y9
  repo: KL-Technologies/therapia-eeg-hrv-kicad
  board_file: board/Therapia_EEG-HRV.kicad_pcb
  status: "not manufactured: Y8 (the 2026-08-29 cart) was never paid and is withdrawn -- 106 vias in SMD openings (ACCEPTANCE I, 2026-09-23). Y9 is the corrected package. Kept as the second product in the Core equivalence proof and as a fixture (open_questions Q7, ruling E-1)."
host:
  kind: standalone
  note: No host module and therefore no M-Bus contract.
board:
  coordinate_system:
    origin: kicad_absolute
    y_axis: down
    note: Unlike m5stack this board has no contract coordinate system; it was imported from EasyEDA and the absolute KiCad grid is what every measurement refers to.
    # The drill/place origin the IPC-D-356 export was written from, in board mm.
    # This board exported from (120, 80), not KiCad's default; S8 measures every
    # d356 coordinate from it (escalation 007).
    drill_origin_mm: [120.0, 80.0]
  holes:
    copper_keepout_margin_mm: 0.2
    copper_margin_mm: 0.2
    npth:
      - [PEG2, 176.861075, -108.097861, 0.7]
      - [PEG1, 176.861075, -113.877885, 0.7]
      - [H1, 123.048, -83.048, 2.3876]
      - [H2, 176.9468, -83.048, 2.3876]
      - [H3, 123.048, -121.9608, 2.3876]
      - [H4, 176.9468, -121.9608, 2.3876]
  # --- added 2026-09-23 (harness S6/S7/S8 safety gates, Q474) ---------
  # ACCEPTANCE D: "PTH 16" (J2's 12 pins + J1's 4 shell legs), measured by
  # scripts/50_final_check.py as PTH_PADS and unchanged since S2.
  pth_pads: 16
  # The order: 1.6 mm (gates/S9.json items[0].spec, data/order_spec.json).
  thickness_mm: 1.6
  outline:
    h_mm: 45.0088
    tolerance_mm: 0.01
    w_mm: 61.8236
fab:
  vendor: jlcpcb
  # --- added 2026-09-23 (harness S7/S8 safety gates, Q474) --------------
  # The order as it stands in the cart (gates/S9.json), as a file S7 and S9
  # read. Via Covering is Plugged: JLC no longer offers Tented and replaced it
  # with Plugged free of charge (2026-09-23, fab/jlc_cart_2026-09-23_y9/02_*).
  # Plugged is solder mask in the hole, not a fill and cap, so the Y9 fix still
  # keeps every via out of the pads (ACCEPTANCE I).
  order_spec: data/order_spec.json
  # What scripts/60_export_fab.sh writes for a human to look at. There is no
  # iso preview: 60_export_fab.sh renders top and bottom only.
  human_facing:
    - preview_top.png
    - preview_bottom.png
    - assembly_top.pdf
  # Every fitted part is on the top (ACCEPTANCE F; B.Paste is empty).
  pcba_side: Top
  # Does this design have custom design rules of its own?
  # `required`: board/Therapia_EEG-HRV.kicad_dru holds them, and a DRC run
  # without that file measures the board against KiCad's defaults, so it is
  # refused. `none`: the design declares none and DRC runs anyway. It is a
  # declaration because it cannot be looked up -- a design with no custom
  # rules and one that lost its rules file are the same directory
  # (Q120, escalation 026, ruling (b)).
  custom_rules: required
  layers: 4
  copper_layers:
    - F.Cu
    - In1.Cu
    - In2.Cu
    - B.Cu
  layer_roles:
    F.Cu: signal
    In1.Cu: ground
    In2.Cu: power
    B.Cu: signal
  via:
    in_pad_policy: forbidden
    # Plugged (JLC, 2026-09-23): solder mask in the barrel, no fill or cap.
    # S7_viapad reads it as an open barrel and keeps judging (barrel_is_closed).
    covering: Plugged
    # Decision, 2026-09-23 (ACCEPTANCE I): a PTH hit with a drill at most this
    # is a via, larger is a component hole. Vias here are 0.305 mm, the
    # smallest component hole is 0.6 mm. The harness's S7_viapad needs it to
    # read the drill file; scripts/67_viapad_gate.py uses the same 0.5.
    drill_max_mm: 0.5
    minimum:
      annular_mm: 0.076
      diameter_mm: 0.45
      drill_mm: 0.3
    standard:
      diameter_mm: 0.6096
      drill_mm: 0.3048
  qty_pcb: 5
  qty_pcba: 2
  clearance:
    preferred_mm: 0.127
    standard_mm: 0.0889
  copper_extensions:
    - gtl
    - g1
    - g2
    - gbl
  edge_clearance_mm: 0.2
  gerber_extension_to_layer:
    gtl: F.Cu
    g1: In1.Cu
    g2: In2.Cu
    gbl: B.Cu
    gts: F.Mask
    gbs: B.Mask
    gtp: F.Paste
    gbp: B.Paste
    gto: F.SilkS
    gbo: B.SilkS
    gm1: Edge.Cuts
  hole_to_copper_mm: 0.2
  hole_to_hole_mm: 0.2
  mask:
    min_width_mm: 0.0508
    pad_to_mask_mm: 0.0508
  paste:
    pad_to_paste_mm: 0.0
  track:
    min_mm: 0.0889
    power_mm: 0.254
    signal_mm: 0.2032
packs:
  afe-adc:
    adc_ref: U_ADS
    adc_part: ADS1299
    zero_via_nets: []
    note: Rev.A predates the per-net copper rules; C1-C4 were never written for this board.
    # --- added 2026-09-23: the twenty keys params.schema.json requires -----
    # Each transcribed from this board's contract (contract/netlist_contract.
    # json), its own scripts, or the ADS1299 datasheet as quoted in
    # docs/ads1299_layout_checklist.md and the pack checklist. Nothing guessed.
    # SBAS499 12.1 (checklist J1): no via between a VCAP/VREF bypass cap and
    # the device -- a class of nets, hence prefixes.
    no_via_in_span_prefixes: [VCAP, VREF]
    # All eight channels are wired to electrodes in the contract: R_IN<n>P
    # pin 1 is FP1/FP2/CH3/ECGP/CH5-CH8_ELEC, R_IN<n>N pin 1 is SRB1 (IN4N:
    # ECGN_ELEC). SRB1 is the common reference. No channel is dead.
    live_analog_nets: [IN1P, IN1N, IN2P, IN2N, IN3P, IN3N, IN4P, IN4N,
                       IN5P, IN5N, IN6P, IN6N, IN7P, IN7N, IN8P, IN8N, SRB1]
    diff_cap_ref_prefix: C_DIF          # C_DIF1..C_DIF8 on the board
    capacitor_ref_prefix: C_            # every capacitor designator is C_*
    series_resistor_ref_prefix: R_      # R_ + IN1P = R_IN1P
    # The prefixes of nets.power_nets below (the supply nets of this board).
    supply_prefixes: [AVDD, AVSS, DVDD, VCAP, VREF, GND, CHASSIS_GND, VNEG,
                      V_NLDO, V_PLDO, V5_LM, V_3V3, VDD_ESP, USB_5V, USB_VBUS,
                      LM_CAP]
    # scripts/47_layout_quality.py SPI (checklist J5: SCLK/DIN/DOUT/CS/DRDY)
    spi_nets: [ADS_SCLK_LOC, ADS_DIN_LOC, ADS_DOUT_LOC, ADS_CS_N, ADS_DRDY_N]
    # the one ground plane (In1.Cu GND); 47_layout_quality.py J5 probes GND
    ground_nets: [GND]
    # AVDD1 (pin 54) and AVSS1 (pin 53) sit on AVDD and AVSS in the contract:
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

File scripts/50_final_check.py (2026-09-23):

#!/usr/bin/env python3
"""S7d -- ACCEPTANCE.md A to G, mechanised.

    KPY scripts/50_final_check.py        (run OUTSIDE the command sandbox)

ACCEPTANCE.md is frozen and this is its implementation. Nothing here relaxes a
criterion; where the document names a number, that number is written out below
next to the measurement, so a reader can check the code against the document
rather than trusting that it was read correctly.

Run after 60_export_fab.sh and 61_make_bom_cpl.py -- D, E, F and G all read the
package those produce.

Result: gates/S7.json.
"""

import argparse
import csv
import json
import os
import shutil
import subprocess
import sys
import tempfile

sys.path.insert(0, os.path.join(os.path.dirname(os.path.abspath(__file__)),
                                "lib"))

import repair as P                                 # noqa: E402
import drc as D                                    # noqa: E402
import epro as E                                   # noqa: E402

HERE = os.path.dirname(os.path.abspath(__file__))

# ACCEPTANCE A: types allowed to remain, at warning severity.
ALLOWED_WARNINGS = {
    "courtyards_overlap", "silk_overlap", "silk_over_copper",
    "silk_edge_clearance", "starved_thermal", "track_dangling", "via_dangling",
    "isolated_copper", "copper_sliver", "holes_co_located",
    "footprint_type_mismatch",
    # ACCEPTANCE C makes the 5 mil track-to-track recommendation a warning; the
    # error-level 0.0889 mm rule stays an error and is counted as one.
    "clearance",
}
# ACCEPTANCE A: must still be errors. If any of these appears at warning
# severity the rules have been relaxed and the document is void.
MUST_BE_ERRORS = {
    "clearance", "hole_clearance", "hole_to_hole", "hole_near_hole",
    "copper_edge_clearance", "shorting_items", "tracks_crossing",
    "unconnected_items", "track_width", "annular_width",
    "drill_out_of_range", "invalid_outline", "items_not_allowed", "padstack",
    "solder_mask_bridge", "zone_has_empty_net", "zones_intersect",
    "malformed_courtyard", "through_hole_pad_without_hole",
    "connection_width", "creepage",
}

# ACCEPTANCE C, verbatim.
RULES_MM = {
    "min_clearance": 0.0889,
    "min_track_width": 0.0889,
    "min_hole_to_hole": 0.2,
    "min_hole_clearance": 0.2,
    "min_copper_edge_clearance": 0.2,
    "min_through_hole_diameter": 0.3,
    "min_via_annular_width": 0.076,
    "min_via_diameter": 0.45,
}
PAD_TO_MASK_MM = 0.0508
PAD_TO_PASTE_MM = 0.0

CONTRACT_PARTS = 135
FITTED_PARTS = 133                      # 135 minus the two DNP
MECHANICAL = ["H1", "H2", "H3", "H4", "PEG1", "PEG2"]
PTH_PADS = 16


def board_side(root, log):
    """A, B and the board half of C and D, measured in this process."""
    import pcbnew
    board = pcbnew.LoadBoard(P.board_path(root))
    diffs, mech = P.contract_diff(board, pcbnew, root)
    facts = {
        "counts": P.counts(board, pcbnew),
        "contract_diffs": diffs,
        "mechanical": mech,
        "unconnected": P.unconnected_count(pcbnew, board),
        "npth": sorted(({"ref": k, "x_mm": P.mm(v[0]), "y_mm": P.mm(v[1]),
                         "dia_mm": P.mm(2 * v[2])}
                        for k, v in P.npth_holes(pcbnew, board).items()),
                       key=lambda d: d["ref"]),
    }
    zones = []
    for z in board.Zones():
        if z.GetIsRuleArea():
            continue
        filled = 0
        for layer in z.GetLayerSet().CuStack():
            try:
                f = z.GetFilledPolysList(layer)
            except Exception:
                continue
            if f is not None:
                filled += f.OutlineCount()
        zones.append({"net": z.GetNetname(), "filled_outlines": filled})
    facts["zones"] = zones
    facts["zones_all_filled"] = all(z["filled_outlines"] > 0 for z in zones)

    ds = board.GetDesignSettings()
    facts["pad_to_mask_mm"] = P.mm(ds.m_SolderMaskExpansion)
    facts["solder_mask_min_width_mm"] = P.mm(ds.m_SolderMaskMinWidth)
    facts["pad_to_paste_mm"] = P.mm(ds.m_SolderPasteMargin)

    dnp = sorted(fp.GetReference() for fp in board.GetFootprints()
                 if fp.IsDNP())
    facts["dnp"] = dnp
    # ACCEPTANCE B, as the handover words it: a DNP part is still a component
    # and its pads still have to match the contract.
    have, _m = P.pad_net_map(board, pcbnew)
    facts["dnp_pads_checked"] = sorted(d for d in dnp if d in have)
    log["board"] = facts
    return facts


def rules_idempotent(root, log):
    """ACCEPTANCE C: regenerating the rules must change nothing.

    Done on a copy so a generator that is NOT idempotent cannot damage the real
    board on the way to reporting that it is not idempotent.
    """
    tmp = tempfile.mkdtemp(prefix="rulecheck")
    try:
        for d in ("board", "contract", "logs"):
            src = os.path.join(root, d)
            if os.path.isdir(src):
                shutil.copytree(src, os.path.join(tmp, d))
        proc = subprocess.run(
            [sys.executable, os.path.join(HERE, "14_make_rules.py"),
             "--root", tmp], capture_output=True, text=True)
        out = {"ran": proc.returncode == 0,
               "stderr": (proc.stderr or "")[-400:]}
        for ext in ("kicad_pro", "kicad_dru"):
            a = os.path.join(root, "board", "%s.%s" % (P.BOARD_NAME, ext))
            b = os.path.join(tmp, "board", "%s.%s" % (P.BOARD_NAME, ext))
            same = (os.path.exists(b)
                    and open(a, "rb").read() == open(b, "rb").read())
            out[ext] = {"identical": bool(same)}
        out["identical"] = all(out[e]["identical"]
                               for e in ("kicad_pro", "kicad_dru"))
        log["rules_regenerated"] = out
        return out
    finally:
        shutil.rmtree(tmp, ignore_errors=True)


def rule_values(root, log):
    pro = E.load_json(os.path.join(root, "board",
                                   P.BOARD_NAME + ".kicad_pro"))
    rules = pro.get("board", {}).get("design_settings", {}).get("rules", {})
    got = {k: rules.get(k) for k in RULES_MM}
    log["rule_values"] = {"wanted": RULES_MM, "got": got}
    return all(abs((got.get(k) or -1) - v) < 1e-9 for k, v in RULES_MM.items())


def fab_side(root, log):
    """D, E, F, G -- read back from the exported package."""
    proc = subprocess.run(
        [sys.executable, os.path.join(HERE, "62_check_fab.py"),
         "--root", root, "--json"], capture_output=True, text=True)
    try:
        fab = json.loads(proc.stdout)
    except ValueError:
        fab = {"error": (proc.stderr or proc.stdout)[-800:]}
    log["fab"] = fab

    bom_path = os.path.join(root, "fab", "BOM_JLCPCB.csv")
    cpl_path = os.path.join(root, "fab", "CPL_JLCPCB.csv")
    bom = {"exists": os.path.exists(bom_path)}
    if bom["exists"]:
        with open(bom_path) as f:
            rows = list(csv.DictReader(f))
        refs = []
        for r in rows:
            refs += [x.strip() for x in r["Designator"].split(",") if x.strip()]
        bom.update(rows=len(rows), parts=len(refs),
                   duplicate_designators=sorted(
                       {x for x in refs if refs.count(x) > 1}),
                   without_lcsc=[r["Designator"] for r in rows
                                 if not r["LCSC Part #"].strip()],
                   designators=sorted(refs))
    cpl = {"exists": os.path.exists(cpl_path)}
    if cpl["exists"]:
        with open(cpl_path) as f:
            rows = list(csv.DictReader(f))
        cpl.update(rows=len(rows),
                   designators=sorted(r["Designator"] for r in rows),
                   sides=sorted({r["Layer"] for r in rows}))
    log["bom"] = {k: v for k, v in bom.items() if k != "designators"}
    log["cpl"] = {k: v for k, v in cpl.items() if k != "designators"}
    if bom.get("designators") and cpl.get("designators"):
        log["bom_cpl_match"] = bom["designators"] == cpl["designators"]
        log["bom_only"] = sorted(set(bom["designators"])
                                 - set(cpl["designators"]))
        log["cpl_only"] = sorted(set(cpl["designators"])
                                 - set(bom["designators"]))
    previews = {n: os.path.join(root, "fab", n)
                for n in ("preview_top.png", "preview_bottom.png")}
    log["previews"] = {n: {"exists": os.path.exists(p),
                           "bytes": os.path.getsize(p)
                           if os.path.exists(p) else 0}
                       for n, p in previews.items()}
    return fab, bom, cpl


def main():
    ap = argparse.ArgumentParser(description=__doc__)
    ap.add_argument("--root", default=P.ROOT)
    ap.add_argument("--no-drc", action="store_true")
    a = ap.parse_args()
    root = a.root
    log = {}

    # --- A ----------------------------------------------------------------
    drc = {}
    if not a.no_drc:
        out = os.path.join(root, "logs", "drc_final.json")
        got, _proc, blob = P.run_drc(out, root)
        if not got:
            print("DRC produced no report -- run outside the sandbox")
            print(blob[-1200:])
            return 2
        doc = P.load_drc(out)
        drc = D.summarize(doc, "error")
        drc["types_at_warning"] = sorted(
            {v["type"] for v in doc.get("violations", ())
             if v.get("severity") == "warning"})
        drc["disallowed_warning_types"] = sorted(
            set(drc["types_at_warning"]) - ALLOWED_WARNINGS)
        # A type on the must-stay-error list appearing only as a warning would
        # mean the severity was relaxed. `clearance` is on both lists by
        # design: ACCEPTANCE C creates a second, advisory 5 mil rule.
        drc["relaxed_error_types"] = sorted(
            (set(drc["types_at_warning"]) & MUST_BE_ERRORS) - {"clearance"})
        log["drc"] = drc

    facts = board_side(root, log)
    idem = rules_idempotent(root, log)
    values_ok = rule_values(root, log)
    fab, bom, cpl = fab_side(root, log)

    npth_ok = fab.get("npth", {}).get("ok")
    ipc = fab.get("ipc_d356", {})
    gj = fab.get("gbrjob", {})
    odb = fab.get("odb", {})
    checks = [
        # A
        P.check("A DRC errors", 0, drc.get("errors"), ok=drc.get("errors") == 0
                if drc else None),
        P.check("A unconnected items", 0, drc.get("unconnected"),
                ok=drc.get("unconnected") == 0 if drc else None),
        P.check("A warning types all on the allowed list", [],
                drc.get("disallowed_warning_types", [])),
        P.check("A no must-be-error type demoted to warning", [],
                drc.get("relaxed_error_types", [])),
        P.check("A zones refilled and saved", True, facts["zones_all_filled"]),
        # B
        P.check("B contract parity (overrides applied)", 0,
                len(facts["contract_diffs"])),
        P.check("B components on the contract", CONTRACT_PARTS,
                facts["counts"]["footprints"] - len(MECHANICAL)),
        P.check("B mechanical footprints excluded", MECHANICAL,
                facts["mechanical"]),
        P.check("B DNP parts still checked against the contract",
                ["R_IO15_DN", "R_RST_UP"], facts["dnp_pads_checked"]),
        P.check("B net set agrees in IPC-D-356", True,
                ipc.get("nets", {}).get("match"),
                note="the d356 designator field is 6 characters and this "
                     "board has 12-character designators, so the pad map is "
                     "not recoverable from it -- the net set is, because the "
                     "net field is 14 and the longest name here is 14"),
        P.check("B net set agrees in ODB++", ipc.get("nets", {}).get(
            "in_contract"), odb.get("nets")),
        P.check("B Gerber X2 names the same net on every top pad", True,
                ipc.get("gerber_x2_agreement", {}).get("ok"),
                note="read through the sticky-attribute state machine: KiCad "
                     "emits %TO.N% only on a change, so most flashes inherit"),
        # C
        P.check("C rules regenerate identically", True, idem["identical"]),
        P.check("C rule values match ACCEPTANCE C", True, values_ok),
        P.check("C pad to mask clearance", PAD_TO_MASK_MM,
                facts["pad_to_mask_mm"]),
        P.check("C pad to paste clearance", PAD_TO_PASTE_MM,
                facts["pad_to_paste_mm"]),
        P.check("C solder mask minimum web", PAD_TO_MASK_MM,
                facts["solder_mask_min_width_mm"]),
        # D
        P.check("D NPTH holes on the board", 6, len(facts["npth"])),
        P.check("D NPTH in the drill file, within 2 um of the table", True,
                npth_ok),
        P.check("D no copper inside hole + 0.2 mm (from the Gerbers)", True,
                fab.get("npth_clear")),
        P.check("D PTH pads unchanged", PTH_PADS,
                facts["counts"]["pth_pads"]),
        P.check("D IPC-D-356 agrees: 6 unplated holes in the right places",
                True, ipc.get("npth_ok"),
                note="at the d356 resolution of 2.54 um; the 2 um assertion "
                     "stays with the Excellon file, which is metric"),
        P.check("D IPC-D-356 feature counts", [230, 417, 16, 6],
                [ipc.get("vias"), ipc.get("smd"), ipc.get("through_pads"),
                 ipc.get("npth")],
                note="vias were 239 until L7 moved R_CC1 out of the USB-C "
                     "shell; USB_CC1 has to cross J1's pad column on B.Cu, "
                     "which costs two (gates/S5_L7.json). S7v then took out "
                     "two AVSS vias in the C_VREFP_10n / C_VREFP_100n pads "
                     "that reached no layer but F.Cu -- each sat in a 0.5 mm "
                     "AVSS fill island of its own inside the In2 AVDD pour -- "
                     "241 -> 239 (logs/viapad_fix.json, 'removed'), and "
                     "the C_LM_FLY.1 room edit replaced a two-via B.Cu hop "
                     "with the straight F.Cu line, and S7j took C_VCAP4's two "
                     "vias out when the capacitor moved under its pin, "
                     "239 -> 235; S7d "
                     "removed five vias that touched one layer only, the "
                     "ends of dangling stubs, 235 -> 230 (logs/"
                     "dangling_prune.json). ACCEPTANCE D allows a recorded "
                     "change"),
        # E
        P.check("E gerber set complete", [], fab.get("missing_layers", ["?"])),
        P.check("E four copper layers", 4,
                len([k for k in fab.get("layers", {})
                     if k.endswith(".Cu")])),
        P.check("E outline 61.8236 x 45.0088 mm +/- 0.01", True,
                fab.get("outline", {}).get("ok")),
        P.check("E every file read by our own parser", True,
                fab.get("all_parsed")),
        P.check("E copper layers additive only", True,
                fab.get("copper_all_dark")),
        P.check("E .gbrjob agrees on layers, thickness, stackup and rules",
                True, gj.get("ok")),
        P.check("E .gbrjob layer count", 4, gj.get("layer_number")),
        P.check("E .gbrjob board thickness mm", 1.6,
                gj.get("board_thickness_mm")),
        # F
        P.check("F BOM exists", True, bom.get("exists")),
        P.check("F every BOM row has an LCSC number", [],
                bom.get("without_lcsc", ["?"])),
        P.check("F no designator on two BOM rows", [],
                bom.get("duplicate_designators", ["?"])),
        P.check("F fitted parts in the BOM", FITTED_PARTS, bom.get("parts")),
        P.check("F CPL exists", True, cpl.get("exists")),
        P.check("F CPL rows", FITTED_PARTS, cpl.get("rows")),
        P.check("F BOM and CPL name the same parts", True,
                log.get("bom_cpl_match")),
        # G
        P.check("G top preview rendered", True,
                log["previews"]["preview_top.png"]["exists"]),
        P.check("G bottom preview rendered", True,
                log["previews"]["preview_bottom.png"]["exists"]),
    ]
    P.gate(root, "S7", checks,
           notes="ACCEPTANCE.md A-G. The document is frozen; this is its "
                 "implementation. D and E are settled by lib/gerber_parse.py "
                 "reading the plotted files, not by KiCad reading its own "
                 "output.",
           extra=log)

    bad = [c for c in checks if not c["pass"]]
    print("ACCEPTANCE A-G: %s" % ("PASS" if not bad else
                                  "FAIL (%d)" % len(bad)))
    for c in checks:
        print("  %-1s %-52s %s"
              % ("" if c["pass"] else "!", c["name"],
                 "ok" if c["pass"] else "expected %r got %r"
                 % (c["expected"], c["actual"])))
    return 0 if not bad else 1


if __name__ == "__main__":
    sys.exit(main())

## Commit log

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2026-08-28 S4: apply ECO-1/2/3 to the PCB
    ECO-1 (8 pins): TPS72325 EN moves off GND onto V_NLDO_IN -- the fatal B1 that
    kept AVSS from ever coming up -- plus RESV1 to GND, GPIO1-4 bundled to the
    adjacent GND pin, and VCAP2/VCAP3 onto new nets.
    ECO-1 (4 parts): C_VCAP2/C_VCAP3/C_VCAP3_H/C_VCAP1_H placed and routed.
    ECO-3 (2 parts): C_VCAP1 and C_VREFP_10u to 1206. Both only fit rotated 90.
    ECO-2: values and LCSC numbers, no copper change. All 135 parts now carry
    Value/MPN/LCSC from data/parts_lcsc.csv.
    Result: pad net map == contract (0 diffs), 0 unconnected, DRC errors equal to
    the pre-ECO baseline. Parts 137->141, tracks 1191->1213, vias 238->240.
    lib/route.py does the geometry: every track, via and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
    [Therapia_EEG-HRV.kicad_pcb, parts_lcsc.csv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]
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2026-08-28 docs: record the FB5 resolution -- the contract is right, DVDD is 3.3 V
    The lead settled S2's open question: DVDD is fed at 3.3 V (inside the ADS1299
    1.8-3.6 V range and matching the ESP32's logic level), so FB5 pin1=VDD_ESP /
    pin2=DVDD is the intended design and PROJECT_STATUS.md's '2.5 V common DVDD'
    is the stale text. The board already matches -- FB5 needs no change, and the
    S4 contract diff of 0 covers it.
    ACCEPTANCE.md is frozen, so its criteria are untouched; the correction goes in
    a dated addendum that names the bullet it corrects.
2026-08-28 S5: add DRC work-list parser (lib/viol.py) and board inspector
    29_drc_report.py groups a saved DRC report the way the repairs are organised;
    28_board_inspect.py resolves items by KIID because DRC reports an item's own
    anchor, which for a long track is nowhere near the violation.
    Claude-Session: https://claude.ai/code/session_01431Pn2abKuPv9KnYCZmkiJ
    [28_board_inspect.py, 29_drc_report.py]
2026-08-28 S5: maze router, repair library, connectivity islands
    lib/maze.py: A* on F.Cu/B.Cu with via transitions, checked against the same
    SHAPE::Collide predicate DRC uses and re-verified segment by segment, because
    around the USB-C pegs there is no straight, L or two-via hop to find.
    lib/repair.py: shared rule values, hole-gap measurement, pad reconnection,
    contract parity, and net_components -- an in-process connectivity check, since
    pcbnew cannot LoadBoard twice and a stranded island found after saving costs a
    whole extra run. 27_net_islands.py validates it against DRC (0 unconnected).
    Claude-Session: https://claude.ai/code/session_01431Pn2a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
    [Therapia_EEG-HRV.kicad_pcb]
2026-08-28 S5 L1: move AMS1117 off mounting hole H4, and fix the identity bug behind it
    The regulator's pin 1 (GND) pad had H4's 2.3876 mm drill through its middle.
    Moved +3.25/+1.25 mm; every pad now clears the hole by 0.4335 mm against a
    0.2 mm rule. West and north -- the ECO's directions -- are blocked: pad 4 runs
    into FB3 pin 2 and U_USB pin 8 to the west, and pad 3 into J1 pin 13 and PEG1
    to the north. DRC errors 69 -> 59, unconnected 0, contract parity unchanged.
    The run also turned up why earlier attempts misbehaved: the EasyEDA importer
    gave every instance of a library footprint the same KIID (38 footprints share
    one, and their 38 pin-1 pads share another). route.uid() keyed on that alone,
    so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
    [Therapia_EEG-HRV.kicad_pcb]
2026-08-28 S5 L2: route CHASSIS_GND round mounting hole H1
    The bottom-layer shell-ground track from J2 pin 12 ran 0.508 mm from H1's
    centre, so the 2.3876 mm drill cut it. Re-routed east of the hole in four
    segments, 6.43 mm against 5.84 mm direct, clear by the 0.3 mm target. DRC
    errors 59 -> 57, unconnected 0.
    The router now string-pulls its result: the first version of this detour came
    back as a 25-segment staircase hugging the clearance circle, because an 8-way
    grid has many equal-cost paths and A* returns whichever it reached first.
    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
    [Therapia_EEG-HRV.kicad_pcb]
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2026-08-28 S5 L4: clear the USB-C peg holes PEG1 and PEG2
    PEG1 was a clearance problem and is fixed as one: the VBUS via retreated and
    four tracks re-routed, all clear by 0.22 mm or better against a 0.2 mm rule.
    PEG2 was a topology problem. VBUS reached J1 pin 11 only by squeezing east
    between the peg and the ESP32 UART pair, and every piece of that squeeze sat
    inside the peg's ring -- both endpoints of each track were in there, so
    re-routing between them could not help, and the via had no legal site within
    2.5 mm. Its drill overlapped the peg's by 0.16 mm, so the barrel could not
    form and VBUS would not have reached the board at all. Those seven pieces are
    deleted and pin 11 now feeds from the west,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
    [Therapia_EEG-HRV.kicad_pcb]
2026-08-28 S5: renumber 2625 duplicated KIIDs so DRC can name items correctly
    The EasyEDA importer gave every instance of a library footprint the same KIID:
    231 uuids shared, 38 footprints on one of them. DRC stores the KIIDs of the
    items in a violation and resolves them when it writes the report, so with
    duplicates it named the wrong items -- a solder mask bridge between two pads
    9.3 mm apart, a 0.0420 mm clearance violation between pads 8.9 mm apart, a
    hole clearance between items 7.5 mm apart. Types and counts were always right;
    identification was not, and L5 and the DRC loop work from exactly that.
    After renumbering, every pair in the report is physically adjacent. Board
    verified unchanged: 141 fo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
    [Therapia_EEG-HRV.kicad_pcb]
2026-08-28 S5 L5: pull apart the remaining clearance pinches
    Found geometrically rather than from the DRC report -- lib/repair.clearance_pairs
    asks the same SHAPE::Collide question DRC does and hands back the real items and
    the real gap, instead of an item's anchor at the other end of an 11 mm track.
    27 of 28 pinches fixed: 14 via retreats, 9 track detours, and 4 footprint nudges
    of 0.05-0.15 mm (C_AVSS_B, C_3V3_H, C_VREFP_10n, C_RST_DLY) where both sides
    were pads and nothing else could move. DRC errors 28 -> 4, unconnected 0,
    contract parity unchanged.
    The one left is a pinch the C_RST_DLY nudge created between that part's ground
    pad and the ADS_RESET_N track; the loop marks a pair done once it has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
    [Therapia_EEG-HRV.kicad_pcb]
2026-08-28 S5: close the three solder mask bridges by local margin, not by amendment
    The copper of each bridged pair is 0.114-0.136 mm apart -- above the 0.0508 mm
    minimum web -- so the openings merge only because each is drawn 0.0508 mm
    oversize. Shrinking the margin on the five pads involved to 0.031-0.042 mm
    restores the web with 2 um to spare. ACCEPTANCE C's board-wide 0.0508 mm is
    untouched, and no pad's resist is pulled inside its copper.
    DRC errors 4 -> 1. No Amendments section is needed: none of the bridges was
    geometrically impossible.
    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
    [Therapia_EEG-HRV.kicad_pcb]
2026-08-28 S6 iteration 1: 1 errors, 1 fixed, 0 unresolved
    [Therapia_EEG-HRV.kicad_pcb]
2026-08-28 S6: DRC loop converges -- 0 errors, 0 unconnected
    The loop runs DRC, hands what is left to 41_drc_fix_pass in its own process
    (pcbnew will not LoadBoard twice), commits, and repeats; it stops on clean, 20
    iterations, two passes that resolve nothing, or a violation set it has seen
    before. It judges an iteration by the set of violation signatures, never by the
    count, because kicad-cli returns 525-531 violations for a byte-identical board.
    The first run found a real hole in the fixer: the last clearance violation was
    *at* a track's endpoint, where the ADS_RESET_N line turns west 0.0685 mm from
    C_RST_DLY's own ground pad. No re-route between the same two endpoints can help
    when one endpoint is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
    [34_repair_L5.py, 35_mask_bridges.py, 40_drc_loop.py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]
2026-08-28 S5/S6 docs: record the repairs, the KIID discovery and the S7 handoff
    STATUS now carries the L1-L5 repair table with coordinates, why PEG2 needed a
    topology change rather than a clearance fix, the J1 pad trim, the four 0402
    nudges, the mask-margin table, and the five points that need a person's eye --
    first among them that AMS1117's body now sits over mounting hole H4, because
    west and north are blocked by FB3/U_USB and J1 pin 13/PEG1 and the south-east
    corner is the only free space. No Amendments section: every solder mask bridge
    was actually fixable, so ACCEPTANCE is untouched.
    README gains the S5/S6 steps and a new pitfall section on non-unique KIIDs.
    run.sh runs S5_uuids through S6.
    Co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
    [40_gen_bom_report.py]
2026-08-28 S5: correct the third 'needs a person' point -- it was not a same-net bridge
    The inherited note said C_VCAP1_H shared a solder mask opening with C_AVSS_P37,
    both AVSS, so it could not short. Neither half holds.
    No DRC report in the history ever pairs C_VCAP1_H with C_AVSS_P37; the S4-era
    report said C_VCAP1_H/2 [AVSS] against C_3V3_H/1 [VDD_ESP] -- itself a
    misidentification, since those two pads are 9.3 mm apart. With unique KIIDs the
    real neighbour is C_VREFP_100n/1 [VREFP]: a different net, 0.1142 mm of copper
    between them, and a bridge that can genuinely short.
    It is fixed, not classified away -- the mask margin on both pads came down.
    Across every DRC report taken on this board there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
2026-08-28 S7a: ECO-5 on the copper, BOM corrections on the fields
    ECO-5 moves C_BIAS_INV pad 2 from GND to BIAS_OUT_INT so the capacitor sits
    in parallel with R_BIAS_FB's 1M rather than shunting the BIAS summing node
    to ground (TI SBAS499). The two pads are 5.23 mm apart with both BIAS_INV
    pads on the straight line between them, so the front side is not the way:
    BIAS_OUT_INT already runs an 18.2 mm B.Cu trunk at y=87.7215 directly under
    the part, and the pad reaches it with one via and a 2.69 mm drop.
    The GND via sat under the 0402 land. The replacement via is 0.55 mm west,
    clear of the land, so the drill is no longer under solder -- tracks 1250 ->
    1251, vias unchanged at 239.
    Fields: FB1-FB5 -> C10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
    [Therapia_EEG-HRV.kicad_pcb, parts_lcsc.csv]
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2026-08-28 S7c: measure the layout against the ADS1299 checklist, and take two vias out of the VCAP3 bypass
    Answers docs/ads1299_layout_checklist.md's J1-J11 by measuring the board. The
    checklist opens by warning that TI publishes no numeric distance for decoupling
    placement and that inventing one is wrong, so distances are reported as
    measurements and the pass/fail is taken on J1, which TI does state as a rule.
    Improvement applied: C_VCAP3_H, the 0.1 uF on VCAP3, reached ADS1299 pin 55
    through 5.95 mm and two vias while the 1 uF sat closer at 3.36 mm -- the wrong
    way round for a high-frequency bypass. It now sits 2.10 mm from the pin and
    reaches it with an L entirely on F.Cu. DRC error 0, unconnected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
    [Therapia_EEG-HRV.kicad_pcb]
2026-08-28 S8: the through-hole pads had no solder mask openings at all -- fixed
    Caught by reading the plotted Gerbers with our own parser rather than asking
    KiCad about the board. The bottom solder mask came out 466 bytes: no apertures,
    no flashes, no regions. Empty.
    Every PTH and NPTH pad arrived from the EasyEDA import with a layer set of
    copper only -- F.Cu, B.Cu and thirty inner layers, no F.Mask, no B.Mask. The
    417 SMD pads were fine, so the front mask still had 403 openings and the fault
    was invisible from the board: DRC has nothing to say about a pad that asks for
    no mask opening.
    What it would have meant: the twelve pins of the electrode header J2 and the
    four USB-C shell legs would have com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
    [Therapia_EEG-HRV-B_Cu.gbl, Therapia_EEG-HRV-B_Mask.gbs, Therapia_EEG-HRV-B_Paste.gbp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]
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2026-08-28 S7/S8 docs: record the two order-blocking defects, the reviews and the S9 handoff
    STATUS.md now carries the S7 and S8 record: the ECO-5 routing decision and why
    the front side was not the way, the analog-untouched proof, the ADS1299
    measurements and the one improvement that was worth making, the manufacturing
    package, and what a person still has to look at before adding to cart.
    Two measurements were wrong on the first pass and both are written down as
    lessons rather than quietly fixed: counting bare "no GND fill" points called
    187 via antipads plane splits, and deciding the AVDD1 star connection from a
    via in the pad's island reported a layout fault where the netlist is what
    decides it. Al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
    [Therapia_EEG-HRV-B_Cu.gbl, Therapia_EEG-HRV-B_Mask.gbs, Therapia_EEG-HRV-B_Paste.gbp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]
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2026-08-28 S7/S8: verify the package three ways -- Gerber X2, IPC-D-356 and ODB++
    Adopting the lead's list. The point of all of it is that one file agreeing with
    itself proves nothing; three files written through different code paths
    agreeing does.
    IPC-D-356 (lib/ipcd356.py, 80-column fixed-width, stdlib slices). 678 features:
    239 vias, 417 SMD pads, 16 through pads, 6 NPTH, nothing unparsed. Its net set
    is 79 and the contract's is 79, with no name on either side the other lacks.
    The six unplated holes land on the ACCEPTANCE D coordinates.
    Two limits measured rather than assumed, because both would otherwise produce
    confident wrong answers:
    The reference designator field is 6 characters and this b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
    [50_final_check.py, 63_gate_s8.py]
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2026-08-28 S9: JLC cart saved (no payment) — PCB Y5-10641515A x5 panels + Standard PCBA SMT026082861630 x2; part swaps and placement checks recorded
    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
2026-08-28 S5_L8: U_MCU becomes an ESP32-WROOM-32UE -- the 25.5 mm body was lying across the ADC
    ACCEPTANCE H failed on four pairs and all four were the same fact: the
    ESP32-WROOM-32E's outline is 25.5 mm long, 6.3 mm of it PCB antenna and
    keep-out at the -X end, and that end points at the ADS1299. It reached
    2.81 mm into the ADC's package and covered C_AVDD1_100n, C_AVDD1_10n and
    C_DVDD_P40.
    The lead's decision, recorded in data/bom_fixes_2026-08-28.json: fit the
    ESP32-WROOM-32UE-N4 (C701344) instead. Espressif's datasheet says the pin
    layout is identical except for the keep-out, so all 38 pads stay where they
    are -- this touches no copper at all. 19.2 x 18 x 3.2 mm body, JLC stock
    5,490, Extended/St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
    [Therapia_EEG-HRV.kicad_pcb, parts_lcsc.csv]
2026-08-28 S5_L9: the +0.3 mm nudge on R_IO2_DN / R_IO15_DN is not available, and here is the measurement
    The lead asked for the two GPIO pull-downs to move 0.3 mm east so their pad
    copper would stand 0.2 mm off the 32UE body edge at x 174.213 (it stands
    0.0022 mm off it now), on condition DRC stayed clean.
    It does not. ESP_RXD runs north-south at x 175.2195 on F.Cu, 0.1525 mm wide,
    from y 91.2775 to 103.165 -- through the 0.71 mm corridor between the
    module's castellations and the pull-downs' pad 2, 0.1216 mm from pad 1. A
    0.3 mm move puts pad 1 on top of it and shorts ESP_IO2 (and ESP_IO15) to
    ESP_RXD. The largest move that still meets the 0.0889 mm clearance rule is
    0.030 mm, against the 0.198 mm n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
    [38_nudge_io_pulldowns.py]
2026-08-28 S7_body: ACCEPTANCE H passes -- J1's own peg holes go on the allow list
    With the 32UE body drawn, the only overlaps left are the three that are not
    part-on-part at all: AMS1117 over the H4 screw hole (already recorded as
    decision M1) and J1 over PEG1/PEG2 -- the USB-C receptacle's own NPTH
    locating pegs, which exist as separate footprints only because EasyEDA put
    the drills on the board and 13_fix_import.py had to synthesise them to get
    them into the drill file. A connector's body containing its own peg holes is
    what the peg holes are for.
    gates/S7_body.json: 141 footprints, 3 overlapping pairs, 3 allowed, 0
    part-on-part failures. One tight pair reported and not failed:
    C_3V3_B2 x C_3V3_OUT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
2026-08-28 S8: data/cpl_overrides.json -- U_MCU's placement rotation becomes 90
    A CPL rotation is not a property of the board. It is the angle between our
    footprint and the orientation the assembler's own library holds the part in,
    and for C701344 (ESP32-WROOM-32UE) those disagree by 90 degrees: JLC's
    footprint is drawn with the module's long axis along Y. All 38 pads map onto
    ours after +90, and both take the pad bounding box centre as their origin, so
    Mid X and Mid Y are unchanged.
    The board must not be turned to match -- the copper is right -- so the number
    is corrected on the one file that talks to the assembler.
    61_make_bom_cpl.py now reads data/cpl_overrides.json after the pos export,
    rewrites t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
    [61_make_bom_cpl.py, 63_gate_s8.py]
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2026-08-29 R29: the 2026-08-29 functional review, applied as BOM-only changes
    An independent review found no blocker. Four of its findings can be fixed
    without touching a single track, so they are in; the rest are recorded as
    Rev.A-accepted, firmware-mandatory, or Rev.B.
    C_CM1P..C_CM8N (16) C1588 -> C163508 1nF 50V C0G 0603, was X7R
    C_NLDO_OUT C12530 -> C23733 4.7uF 10V 0402, was 2.2uF 6.3V
    C_LM_IN C52923 -> C23733 same part, was 1uF 25V
    C_AVDD_P59 C1525 -> C52923 1uF 0402, was 100nF
    C_VCAP1 kept, with the reason written down
    The C0G swap is the one that matters: those sixteen sit on the electrode
    input nodes, and X7R is pie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
    [BOM_JLCPCB.csv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]
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2026-08-29 R29-6: the two auto-reset base resistors become 470k, on simulation evidence
    The ngspice case sim/cases/esp32_autoreset.py found ESP_EN idling at 4.238 V
    and ESP_IO0 at 4.203 V against the ESP32's 3.6 V absolute maximum. The CH340C
    runs from USB_5V, so DTR#/RTS# idle at 5 V; both handshake lines high leaves
    each transistor off with its base above its 3.3 V collector, forward-biasing
    the base-collector junction into the 10 k pull-ups.
    The first proposal was 100 k, reasoning that ten times the resistance is a
    tenth of the current. The simulation rejected it. The off-side device is in
    reverse-active mode, so the collector pushes (1 + BR) times the base current
    into the node -- 7.63 uA of base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
    [BOM_JLCPCB.csv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]
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2026-09-04 product.yaml: state the drill/place origin (escalation 007)
    This board exported its IPC-D-356 from (120, 80), not KiCad's default.
    pcbharness.core.ipcd356 no longer carries an ORIGIN_MM default, so the
    S8 gate reads board.coordinate_system.drill_origin_mm from here.
    Claude-Session: https://claude.ai/code/session_01TPCLNA2CZVgooTvXeGY9Pc
    [product.yaml]
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2026-09-05 manifest: fab.custom_rules -- this board has custom design rules (026 (b))
    The harness's DRC gate refused any board that was not beside both its
    .kicad_pro and its .kicad_dru. That is right about the project file and wrong
    about the rules file: a design that declares no custom rules does not have one,
    and the two references the harness reads (KiCad 5 and KiCad 4 designs, from
    before the .kicad_dru format existed) could never be measured at all.
    Whether a design HAS custom rules cannot be looked up -- a board with none and
    a board that lost its rules file are the same directory -- so the manifest says
    it. This board says `required`: board/Therapia_EEG-HRV.kicad_dru is here with
    its three rul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
    [product.yaml]
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2026-09-23 S7p / ACCEPTANCE J: clip the footprints' own paste shapes back onto their pads
    168 of the 178 F.Paste shapes the EasyEDA import drew beside the pads reached
    past the copper (0.134 mm on six 0805s, 0.076 mm each side of every ADS1299
    land). 68_fix_paste_graphics.py replaces each with its intersection with the
    footprint's pads; 69_paste_gate.py checks the uploaded F_Paste against the
    F_Cu pads with its own Gerber reader, with a 0.1 mm-shifted negative control.
    Claude-Session: https://claude.ai/code/session_01BbaSxDrhhKaR1T3EhiM8tM
    [68_fix_paste_graphics.py, 69_paste_gate.py]
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2026-09-23 S7v / ACCEPTANCE I: 0.10 mm between a via drill and any SMD opening
    The placement margin and every tier's drill margin go from 0.03/0.05/0.035
    to 0.10 mm (JLC's guidance; QA MINOR-1 found 20 vias between 0.0327 and 0.1).
    Near-track sites let the IN*N vias sit just off their F.Cu run without
    lengthening the signal path; small steps from 0.025 mm are searched. Four
    boxed-in pads get explicit room edits (U_MCU.16 with U_MCU.14, C_LM_FLY.1,
    FB4.2, R_CC2.2) and D_ESD.3 loses its 0.45 mm stub (MINOR-5). Gate I also
    fails any via drill under 0.10 mm from an SMD opening in the Gerbers.
    Claude-Session: https://claude.ai/code/sessio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
    [66_fix_via_in_pad.py, 67_viapad_gate.py]
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2026-09-23 VCAP1 X5R kept by ruling: recorded in harness Q490 form; bring-up 7-3 measures it
    packs.afe-adc.vcap1_dielectric_ruling (vibration/reason/approved_by/date):
    SBAS499C s.11 is conditional on vibration; ADS1299EVM and Cyton use X5R
    100 uF. Bring-up 7-3 records the VCAP1 DC level and input-short noise at
    rest, worn and moving, and tapped; tantalum A case at Rev.B if it shows.
    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
    [product.yaml]
2026-09-23 Y9 re-export after the QA MINORs: S7p before S7v, S7m and S7_maskweb wired, all gates green
    run.sh: S7p now runs before S7v (clipped paste no longer inflates the
    openings S7v keeps clear of), S7m after S7d, S7_maskweb after S7_paste.
    Via counts 237 -> 232 (IPC-D-356 / ODB++ constants). ACCEPTANCE addendum 5
    (I at 0.10 mm, L), STATUS. Board and fab regenerated from the pre-S7v
    board: DRC 0/0, dangling 0, via-to-opening min 0.1007 mm, no different-net
    dam under 0.10 mm, IN1P-IN8N path change <= 0.0013 mm.
    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
    [Therapia_EEG-HRV-B_Cu.gbl, Therapia_EEG-HRV-B_Mask.gbs, Therapia_EEG-HRV-B_Paste.gbp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]
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2026-09-23 S7v / S7n: copper added in this revision keeps 0.127 mm to other nets
    S7v drops the 0.100 and 0.0889 mm tiers; room edits are checked at 0.127.
    D_ESD.3's UART pair goes to 0.1016 mm between the pad rows (was 0.092 mm
    from the pad row and the USB_DM via), J1.4's via becomes 0.46/0.30, and the
    ADS_RESET_N trunk is shortened in place. S7n measures everything S7v/S7j
    laid: two allowed exceptions (R_CC2.2 via 0.120, the geometric maximum;
    Y8's trunk 0.1018).
    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
    [66_fix_via_in_pad.py, 74_new_copper_clearance.py]
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2026-09-23 S9: Y9 in the JLC cart as Y13 (no payment); via covering is Plugged
    JLC no longer offers Tented and replaces it with Plugged free of charge;
    the lead accepted it. Plugged is solder mask in the hole, not a fill and
    cap, so ACCEPTANCE I still applies and the harness S7_viapad keeps judging
    (16/16). IPC-4761 type left unverified. BOM 31/31 confirmed with 0 LCSC
    differences (U_USB restored to C84681); placement checked against the
    board file. The two Y8 rows stay in the cart until the owner agrees to
    delete them.
    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
    [product.yaml]
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2026-09-23 manifest: C2 exception for the pin-28-side VCAP1 via (harness Q545)
    Harness Q545 judges C2/C3 on the copper path from C_VCAP1 to pin 28; that
    path runs through (147.9095, 106.407), the pin end of the branch already
    declared (ACCEPTANCE.md 追記 8), which the old box stopped short of. One
    entry, applies_to [C3], attributed to the lead, 2026-09-24.
    Measured on git-archive copies with the harness at a9404e9: S5_netconstraints
    5/6 -> 6/6, S5_layout 5/5 and S0_manifest 51/51 unchanged. Board and fab
    untouched.
    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
    [product.yaml]
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
